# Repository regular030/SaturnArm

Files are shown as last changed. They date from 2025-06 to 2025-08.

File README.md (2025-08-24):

<p align="center">
  
  # SaturnArm - A Simple Robotic Arm
</p>

<p align="center">
  
  
  
  
  
  
  [Youtube Video](https://youtu.be/AQZ1tVmb0GA)
  
  <ul>
<p align="center">
  <br>
  BOM: https://docs.google.com/spreadsheets/d/1lf9XG99qlgez3aRTxvFln9WQ-VlTF8MQk1fM6mLnBtQ/edit?usp=sharing
    
  
</p>
    
<h2> Why did I Build This?</h2>
<p>
  While watching a NASA Mars rover in action on YouTube, I noticed how every function, including the robotic arm, was controlled through a computer interface. It made me wonder, why not use virtual reality instead, to make the experience more immersive and intuitive?
</p>

# Files 
- Chassis
  - SaturnArm.gcode.3mf
      - G-code to print out the entire arm for the Bambu Lab A1m
  - arm_pcb.step
    - The PCB's 3D model file
  - Full-Arm.f3z
    - Full Fusion/Fusion 360 file for the arm
  - bot
    - All 3D files for the bottom part of the arm    
  - middle
    - All 3D files for the middle part of the arm    
  - top
    - All 3D files for the top part of the arm
- Kicad
  - All PCB files for KiCad 8.0.5
- Firmware
  - All the Firmware files for the Pi Zero 2 W
- Unity
  -  All the Files for the VR to Arm stuff in Unity 2022.3.38f1
  -  DEPRECATED
      
<ul> </ul>
 
#  Instructions

## Building the Firmware on Raspberry Pi Zero 2 W

**1. Install Required Packages**

Open a terminal on your Pi Zero 2 W and run:
```sh
sudo apt update
sudo apt install -y git cmake g++ libopencv-dev libboost-system-dev pigpio
```

**2. Clone the Repository**
```sh
git clone https://github.com/regular030/SaturnArm
cd SaturnArm/Firmware/Arm
```

**3. Enable pigpio Daemon**
```sh
sudo systemctl enable pigpiod
sudo systemctl start pigpiod
```

**4. Build the Firmware**
```sh
mkdir build
cd build
cmake ..
make -j1
```
The executable `SaturnArm` will be created in the `build` directory.

---

## Calibration

Before using the arm, you must calibrate it:

1. **Remove the Motors:**  
   Remove the motors from the arm.

2. **Run the Firmware:**  
   Start the firmware executable under the build directory:
   ```sh
   sudo ./SaturnArm
   ```

3. **Wait for Program to Run:**  
   Wait for the Program to run, after that wait for the motors to move to 0deg. Once the motors are done moving, make sure the arms are in an upright position before attaching the motors.

---

## Main Functions

- **move_to(x, z):**  
  Move the arm to a specific (x, z) coordinate using inverse kinematics.
     ```sh
   move:(x),(y)
   ```

- **set_servo_angle(servo_number, angle):**  
  Set a specific servo (shoulder, elbow, or claw) to a given angle.
     ```sh
   servo(number):(deg)
   ```

- **emergency_stop():**  
  Immediately stop all motion and disable servos.
  ```sh
   stop
   ```
---

For more details, see the source code in `Firmware/Arm/`.

<ul> </ul>

#  TODO

- Finalize VR Support - Delayed Indefinitely

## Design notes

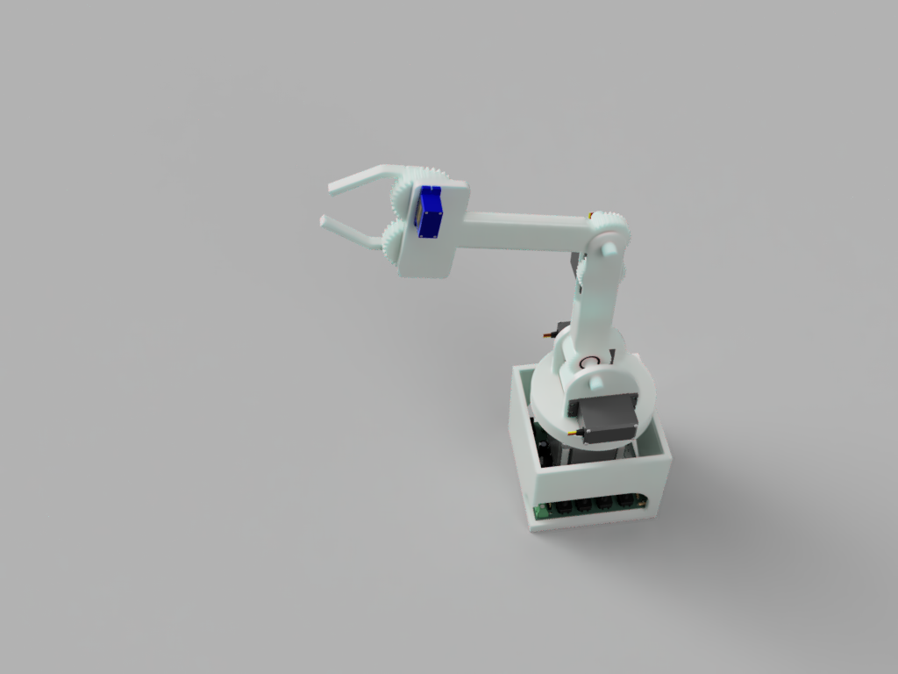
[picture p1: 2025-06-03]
Chassis/arm_2025-Jun-03_09-30-14PM-000_CustomizedView1273378670.png

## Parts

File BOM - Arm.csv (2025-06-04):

Part Name | QTY | Price Per | Link | Notes
Raspberry Pi Zero 2 W(U2) | 1 | US $24.04 | here
LM2596 (U1) | 1 | US $1.54 | here
THT 3 Pin connectors 5 pack | 1 | US $1.84 | here
THT 4 Pin connectors 5 pack | 1 | US $2.11 | here
Mg996r | 3 | US $15.49 | here | servo
Nema23 23HS5628 | 1 | US $25.05 | here
Sg90 | 1 | US $3.29 | here | mini servo
AC 110V - 220V DC 24V 8A | 1 | US $20.07 | here | psu
Rotary Encoder | 5 | US $2.72 | here
Bearing - 6800-2RS 10X19X5 | 4 | US $4.10 | here
75mm M5 screw 10 pack | 1 | US $0.99 | here
M3 M4 M5 screw and nuts pack | 1 | US $16.32 | here
1 kg of PLA white matte | 1 | US $21.87 | here
resistors Pack | 1 | US $3.20 | here | 10k + 1k
2.1mm Jack THT | 1 | US $1.35 | here
DC 24V to DC 6V | 1 | US $7.67 | here
Wire Multiple colours | 1 | US $10.98 | here | 20awg
TMC2208 | 1 | US $4.31 | here | stepper driver
Micro SD card | 1 | US $4.67 | here
Micro USB Male To USB 2.0 Female | 1 | US $2.13 | here
JLCPCB | 5 | US $2.00
Raspberry Pi Model B+ Camera Module | 1 | US $4.51 | here
Tota (Taxes + shipping): | US $151.25 (AliExpress) + USD 31.30$ Bambulab + USD $3.50 (JLC) = $186.05 USD =~ $200 USD

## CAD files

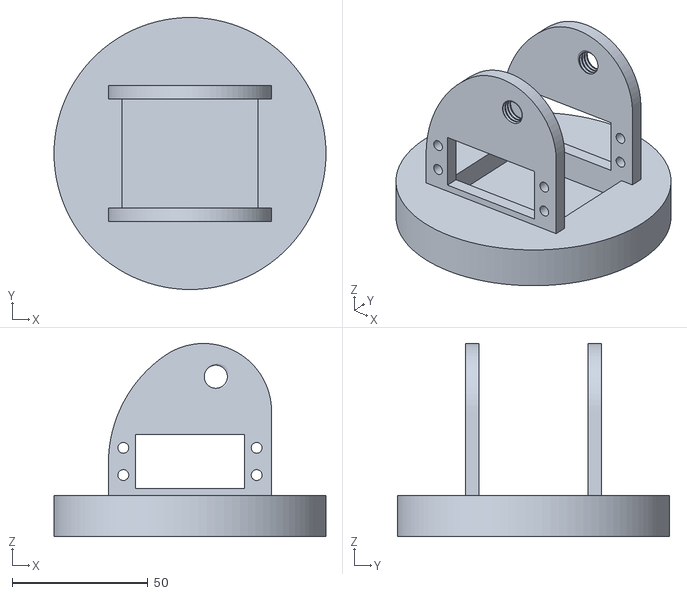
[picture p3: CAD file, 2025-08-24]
Chassis/bot/Arm_Base.stl
100.0 x 100.0 x 71.0

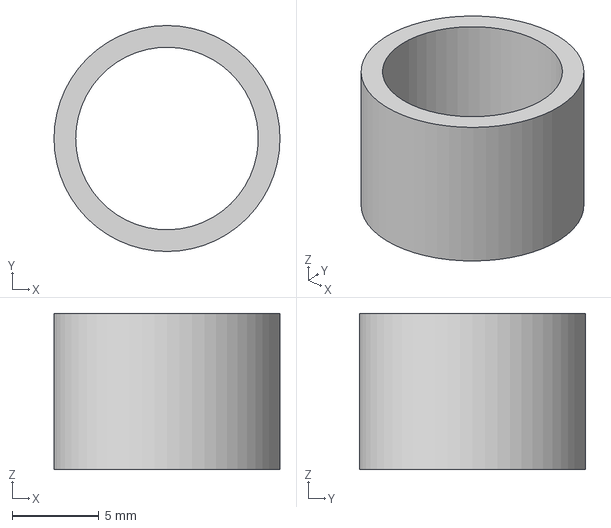
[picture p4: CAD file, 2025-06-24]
Chassis/middle/BearingHolderLow-Spacer.step
13.0 x 13.0 x 9.00 mm

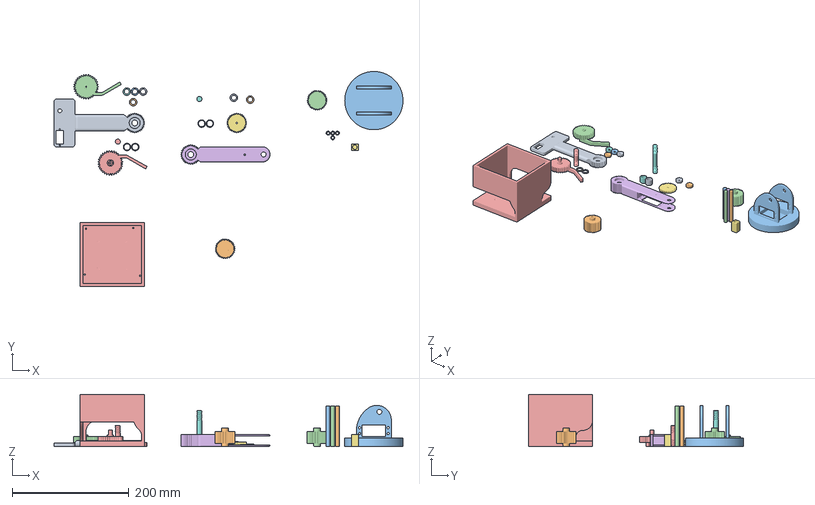
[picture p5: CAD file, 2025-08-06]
Chassis/SaturnArm.gcode.3mf
599.1 x 369.2 x 90.0 mm
arm2.stl
Nut-10mm.step x 6
TopClawL.stl
TopClawR.stl
Arm1.stl
arm-thinGear-Real v9
bearingHolder-Low v13
Arm_Base.stl
PCB_Chassis.stl
Standoff-Bot.stl x 4
Stepper-Insert v7
bearingHolder-middle.step
BearingHolderMiddle-Spacer.step x 2
BearingHolderLow-Spacer.step x 2

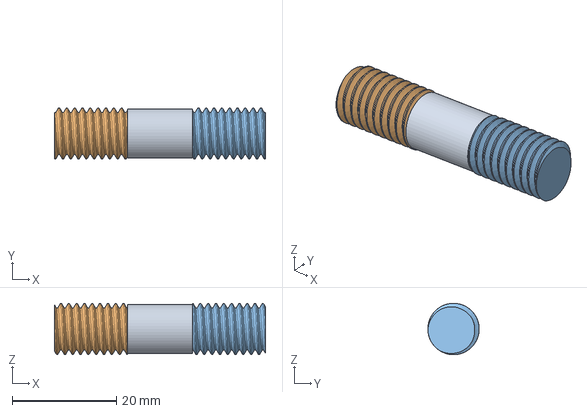
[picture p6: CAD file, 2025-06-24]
Chassis/top/bearingHolder-middle.step
40.5 x 9.86 x 9.86 mm

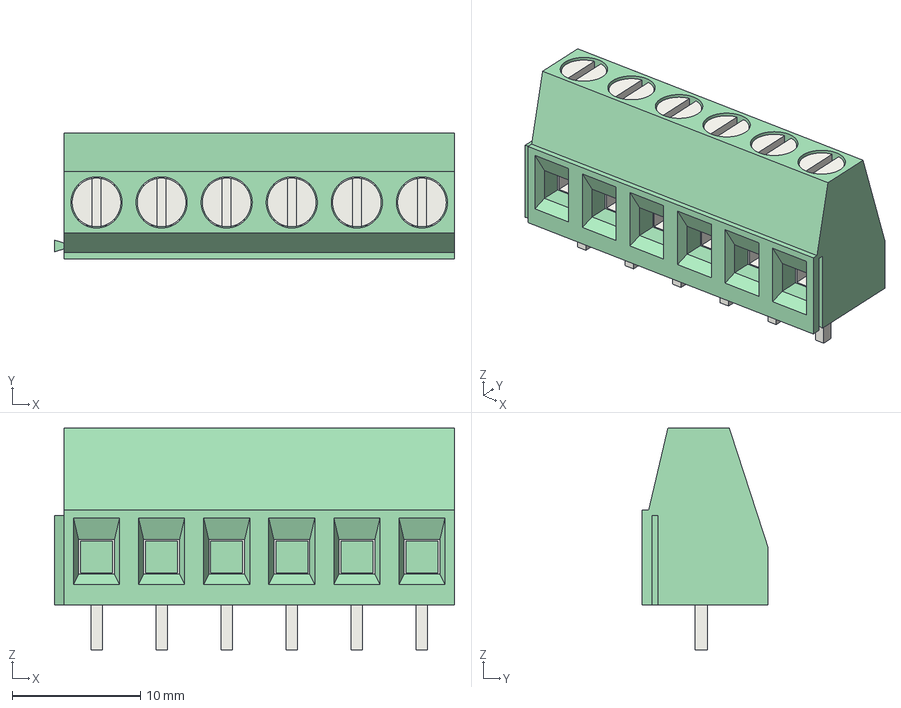
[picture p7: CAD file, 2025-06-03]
Kicad/Files Needed/3dmodels/TerminalBlock_Phoenix_MKDS-1,5-6-5.08_1x06_P5.08mm_Horizontal.step
31.2 x 9.80 x 17.3 mm

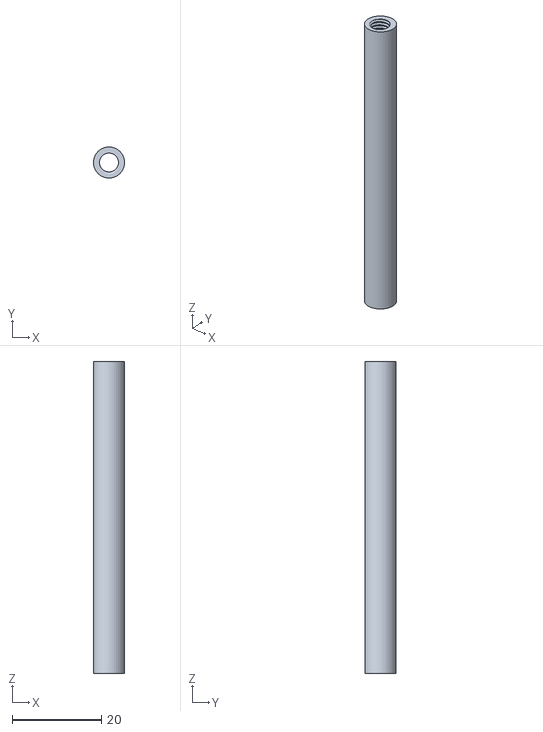
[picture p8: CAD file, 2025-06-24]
Chassis/bot/Standoff-Bot.stl
7.00 x 7.00 x 70.0

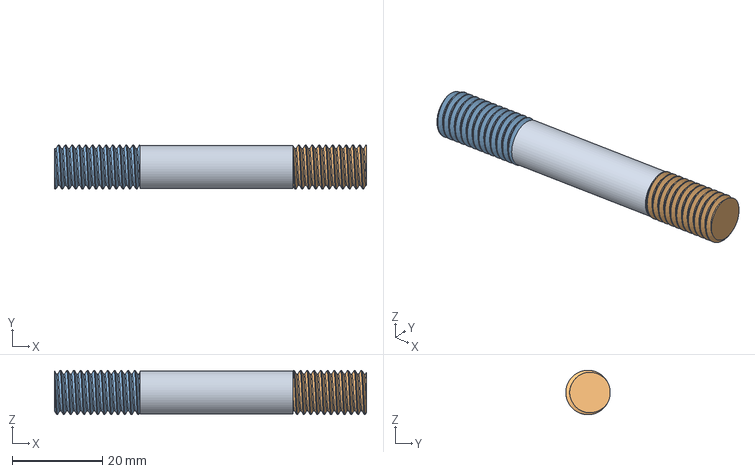
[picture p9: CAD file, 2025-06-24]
Chassis/middle/bearingHolder-Low.step
69.2 x 9.86 x 9.86 mm

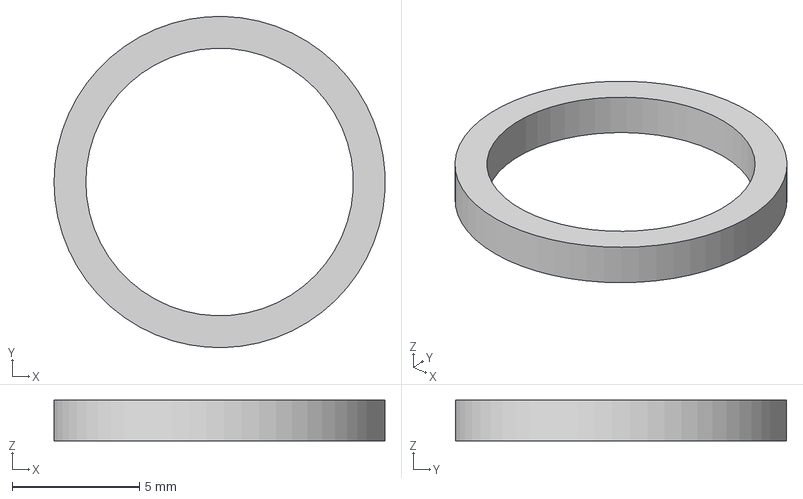
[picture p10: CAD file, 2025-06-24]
Chassis/top/BearingHolderMiddle-Spacer.step
13.0 x 13.0 x 1.60 mm

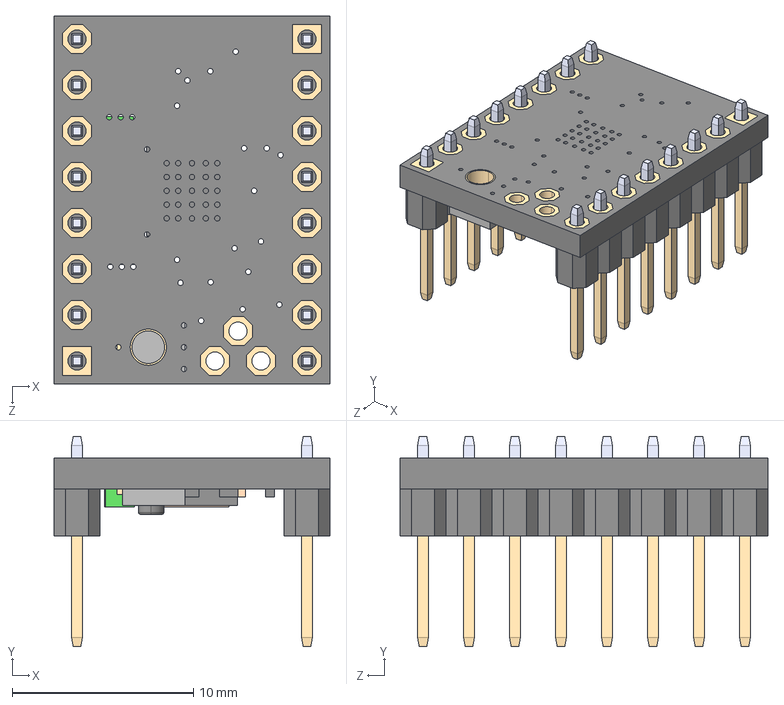
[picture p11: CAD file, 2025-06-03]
Kicad/Files Needed/3dmodels/TMC2208 SILENTSTEPSTICK--3DModel-STEP-1.STEP
15.2 x 11.6 x 20.3 mm

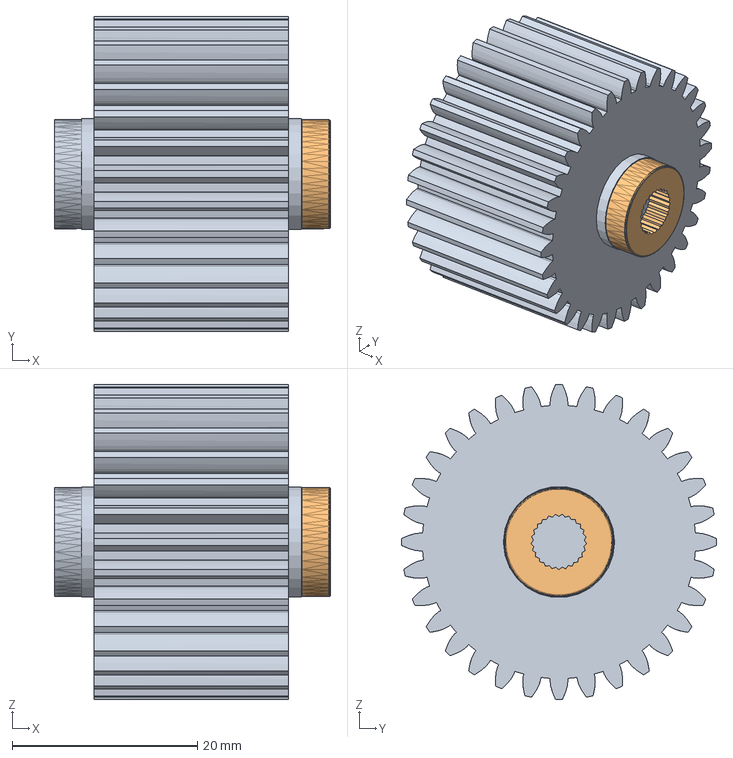
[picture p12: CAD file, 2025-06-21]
Chassis/bot/insert-motor-bot.step
29.8 x 34.0 x 34.0 mm

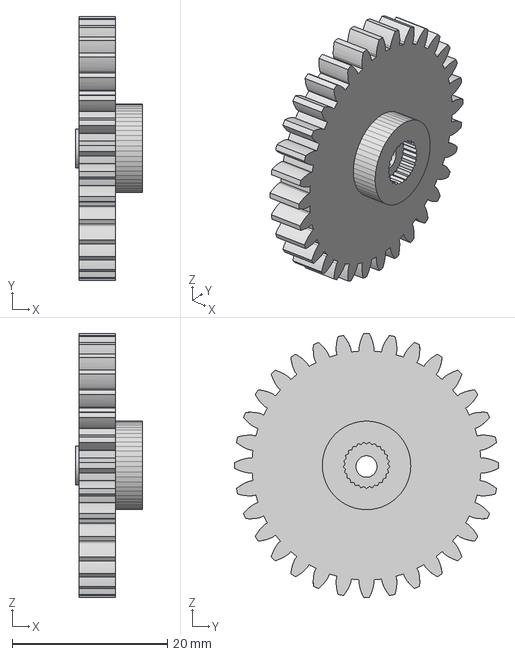
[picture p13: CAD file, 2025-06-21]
Chassis/middle/arm1-thinGear.step
8.67 x 34.0 x 34.0 mm

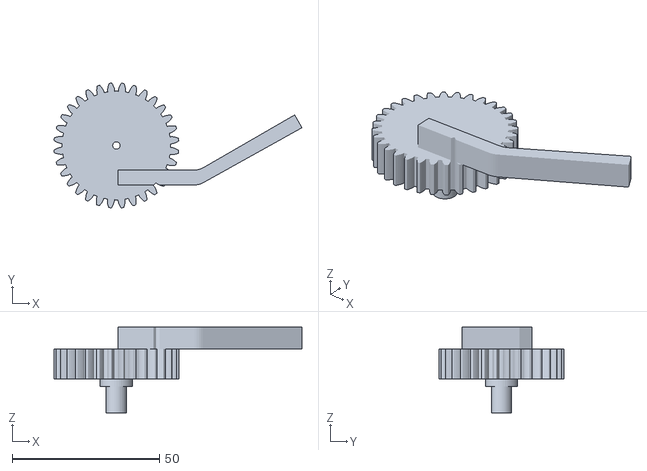
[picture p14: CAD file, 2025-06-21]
Chassis/top/TopClawR.stl
84.2 x 42.4 x 29.1

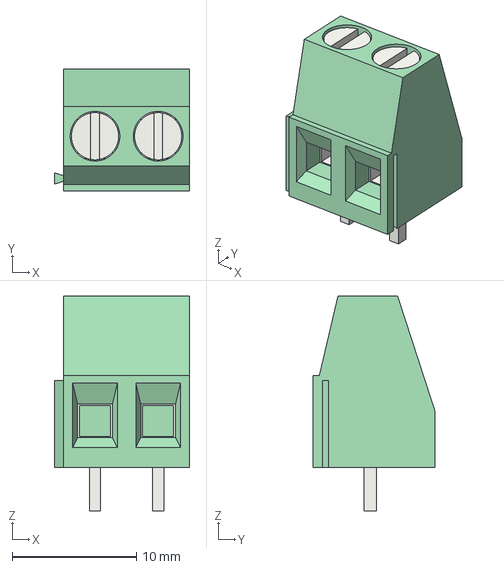
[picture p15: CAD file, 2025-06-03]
Kicad/Files Needed/3dmodels/TerminalBlock_Phoenix_MKDS-1,5-2-5.08_1x02_P5.08mm_Horizontal.step
10.9 x 9.80 x 17.3 mm

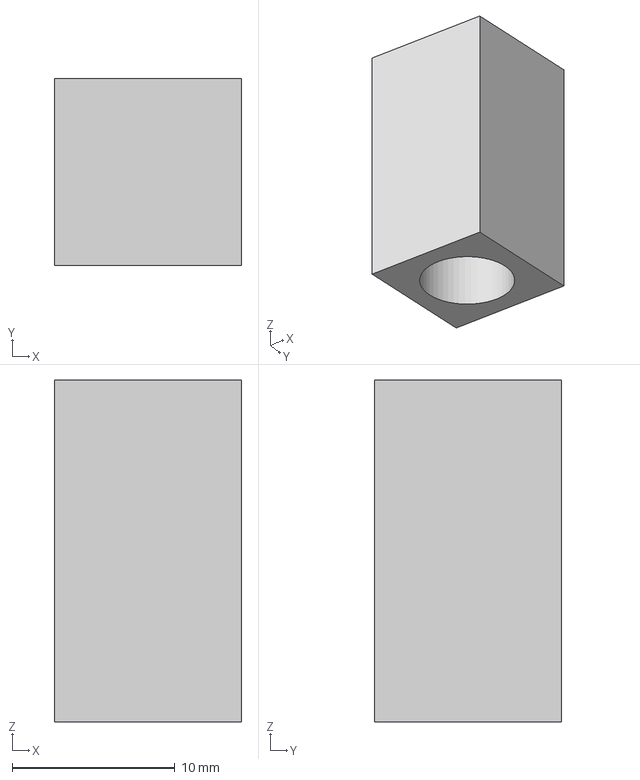
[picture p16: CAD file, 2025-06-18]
Chassis/bot/Stepper-Insert.step
11.5 x 11.5 x 21.0 mm

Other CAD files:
Chassis/top/TopClawL.stl
Kicad/Files Needed/3dmodels/TerminalBlock_Phoenix_MKDS-1,5-3-5.08_1x03_P5.08mm_Horizontal.step
Chassis/bot/PCB_Chassis.stl
Chassis/middle/Arm1.stl
Chassis/middle/Nut-10mm.step
Chassis/top/Nut-10mm.step
Chassis/top/arm2.stl
Kicad/Files Needed/3dmodels/Bourns_-_PEC11R-4220F-S0024.step
Kicad/Files Needed/3dmodels/SN74HC165N.step
Kicad/Files Needed/3dmodels/TerminalBlock_Phoenix_MKDS-1,5-4-5.08_1x04_P5.08mm_Horizontal.step
Kicad/Files Needed/3dmodels/esp32_devkit_v1_doit.step

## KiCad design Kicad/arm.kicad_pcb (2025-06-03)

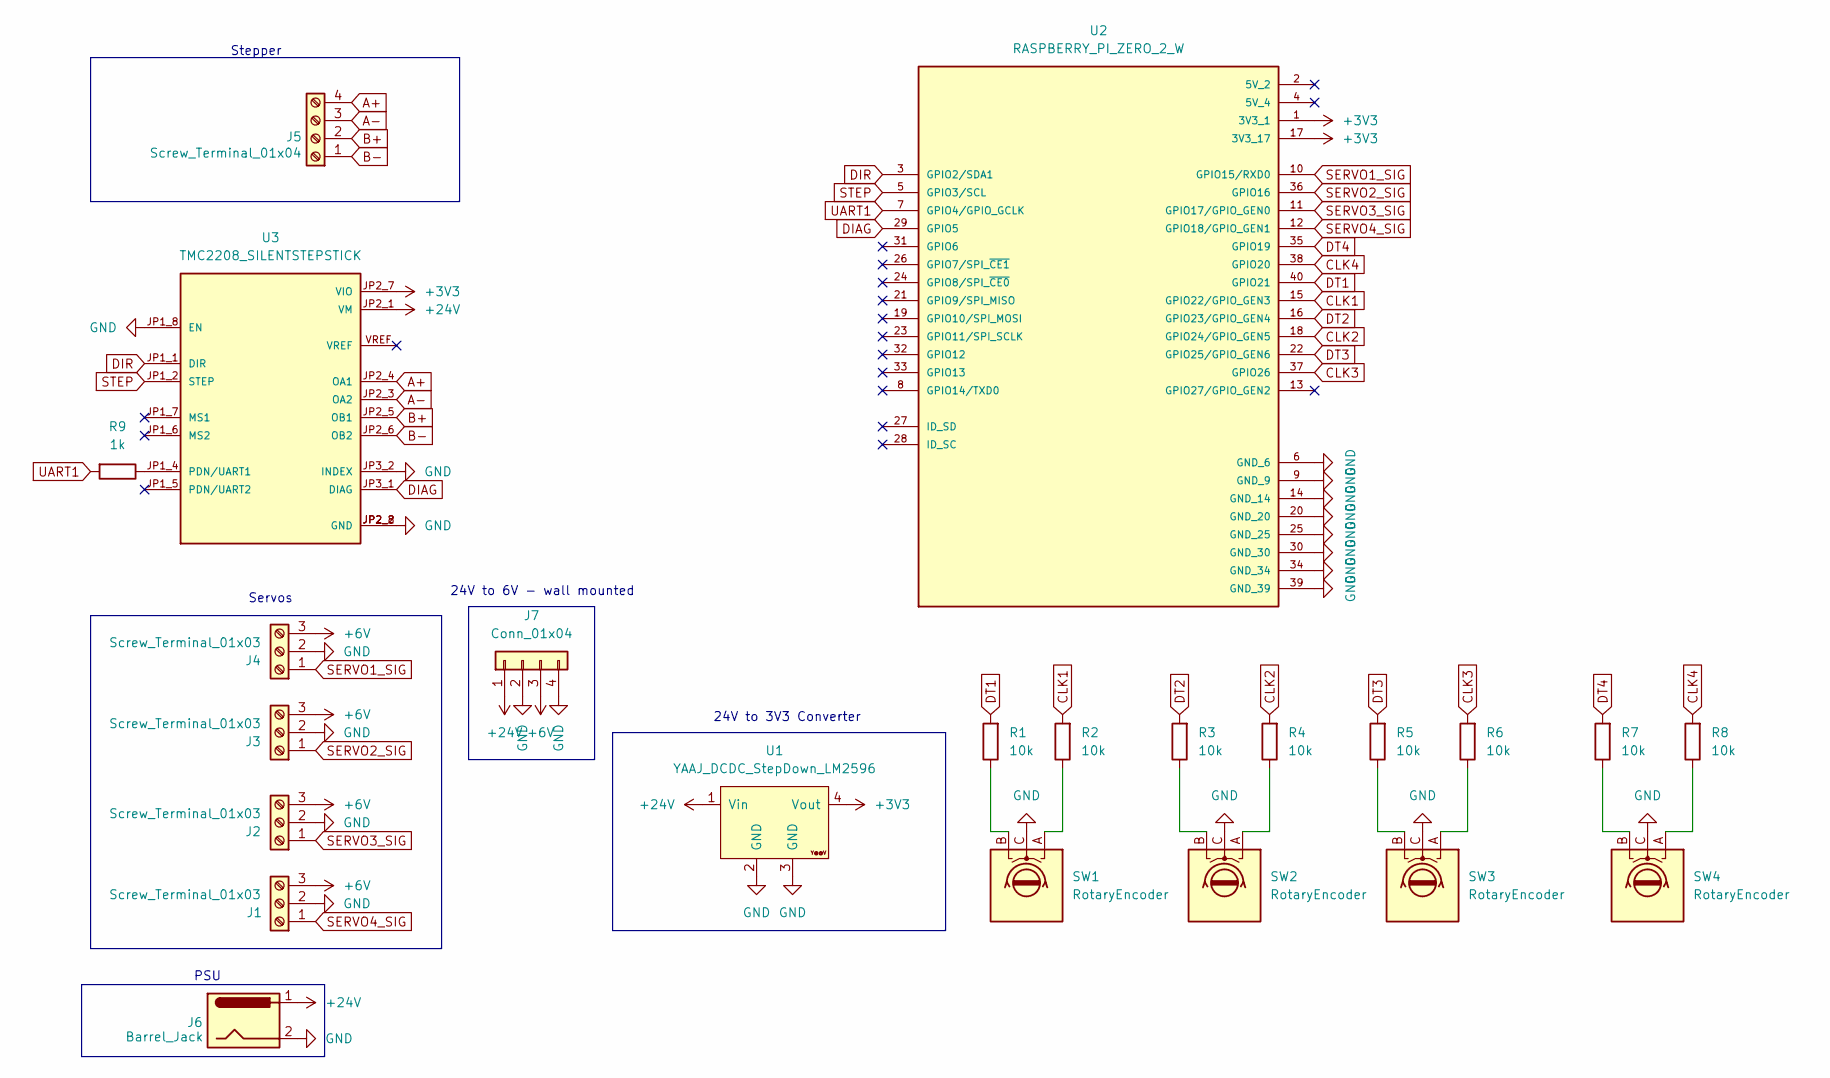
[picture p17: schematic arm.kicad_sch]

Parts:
J1, J2, J3, J4: Screw_Terminal_01x03; TerminalBlock_bornier-3_P5.08mm
J5: Screw_Terminal_01x04; TerminalBlock_bornier-4_P5.08mm
J6: Barrel_Jack; BarrelJack_Horizontal
J7: Conn_01x04; PinHeader_1x04_P2.54mm_Vertical
R1, R2, R3, R4, R5, R6, R7, R8: 10k; R_Axial_DIN0207_L6.3mm_D2.5mm_P7.62mm_Horizontal
R9: 1k; R_Axial_DIN0207_L6.3mm_D2.5mm_P7.62mm_Horizontal
SW1, SW2, SW3, SW4: RotaryEncoder; RotaryEncoder_Alps_EC11E-Switch_Vertical_H20mm
U1: YAAJ_DCDC_StepDown_LM2596
U2: RASPBERRY_PI_ZERO_2_W; MODULE_RASPBERRY_PI_ZERO_2_W; PARTREV April 2024
U3: TMC2208_SILENTSTEPSTICK; MODULE_TMC2208_SILENTSTEPSTICK

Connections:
+3V3: U1.4 (Vout), U2.1 (3V3_1), U2.17 (3V3_17), U3.JP2_7 (VIO)
+6V: J1.3, J2.3, J3.3, J4.3, J7.3
+24V: J6.1, J7.1, U1.1 (Vin), U3.JP2_1 (VM)
A+: J5.4, U3.JP2_4 (OA1)
A-: J5.3, U3.JP2_3 (OA2)
B+: J5.2, U3.JP2_5 (OB1)
B-: J5.1, U3.JP2_6 (OB2)
CLK1: R2.2, U2.15 (GPIO22/GPIO_GEN3)
CLK2: R4.2, U2.18 (GPIO24/GPIO_GEN5)
CLK3: R6.2, U2.37 (GPIO26)
CLK4: R8.2, U2.38 (GPIO20)
DIAG: U2.29 (GPIO5), U3.JP3_1 (DIAG)
DIR: U2.3 (GPIO2/SDA1), U3.JP1_1 (DIR)
DT1: R1.2, U2.40 (GPIO21)
DT2: R3.2, U2.16 (GPIO23/GPIO_GEN4)
DT3: R5.2, U2.22 (GPIO25/GPIO_GEN6)
DT4: R7.2, U2.35 (GPIO19)
GND: J1.2, J2.2, J3.2, J4.2, J6.2, J7.2, J7.4, SW1.C, SW2.C, SW3.C, SW4.C, U1.2 (GND), U1.3 (GND), U2.6 (GND_6), U2.9 (GND_9), U2.14 (GND_14), U2.20 (GND_20), U2.25 (GND_25), U2.30 (GND_30), U2.34 (GND_34), U2.39 (GND_39), U3.JP1_8 (EN), U3.JP2_2 (GND), U3.JP2_8 (GND), U3.JP3_2 (INDEX)
unnamed: R1.1, SW1.B
unnamed: R2.1, SW1.A
unnamed: R3.1, SW2.B
unnamed: R4.1, SW2.A
unnamed: R5.1, SW3.B
unnamed: R6.1, SW3.A
unnamed: R7.1, SW4.B
unnamed: R8.1, SW4.A
unnamed: R9.1, U3.JP1_4 (PDN/UART1)
SERVO1_SIG: J4.1, U2.10 (GPIO15/RXD0)
SERVO2_SIG: J3.1, U2.36 (GPIO16)
SERVO3_SIG: J2.1, U2.11 (GPIO17/GPIO_GEN0)
SERVO4_SIG: J1.1, U2.12 (GPIO18/GPIO_GEN1)
STEP: U2.5 (GPIO3/SCL), U3.JP1_2 (STEP)
UART1: R9.2, U2.7 (GPIO4/GPIO_GCLK)

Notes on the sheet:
Servos
Stepper
24V to 6V - wall mounted
24V to 3V3 Converter
PSU

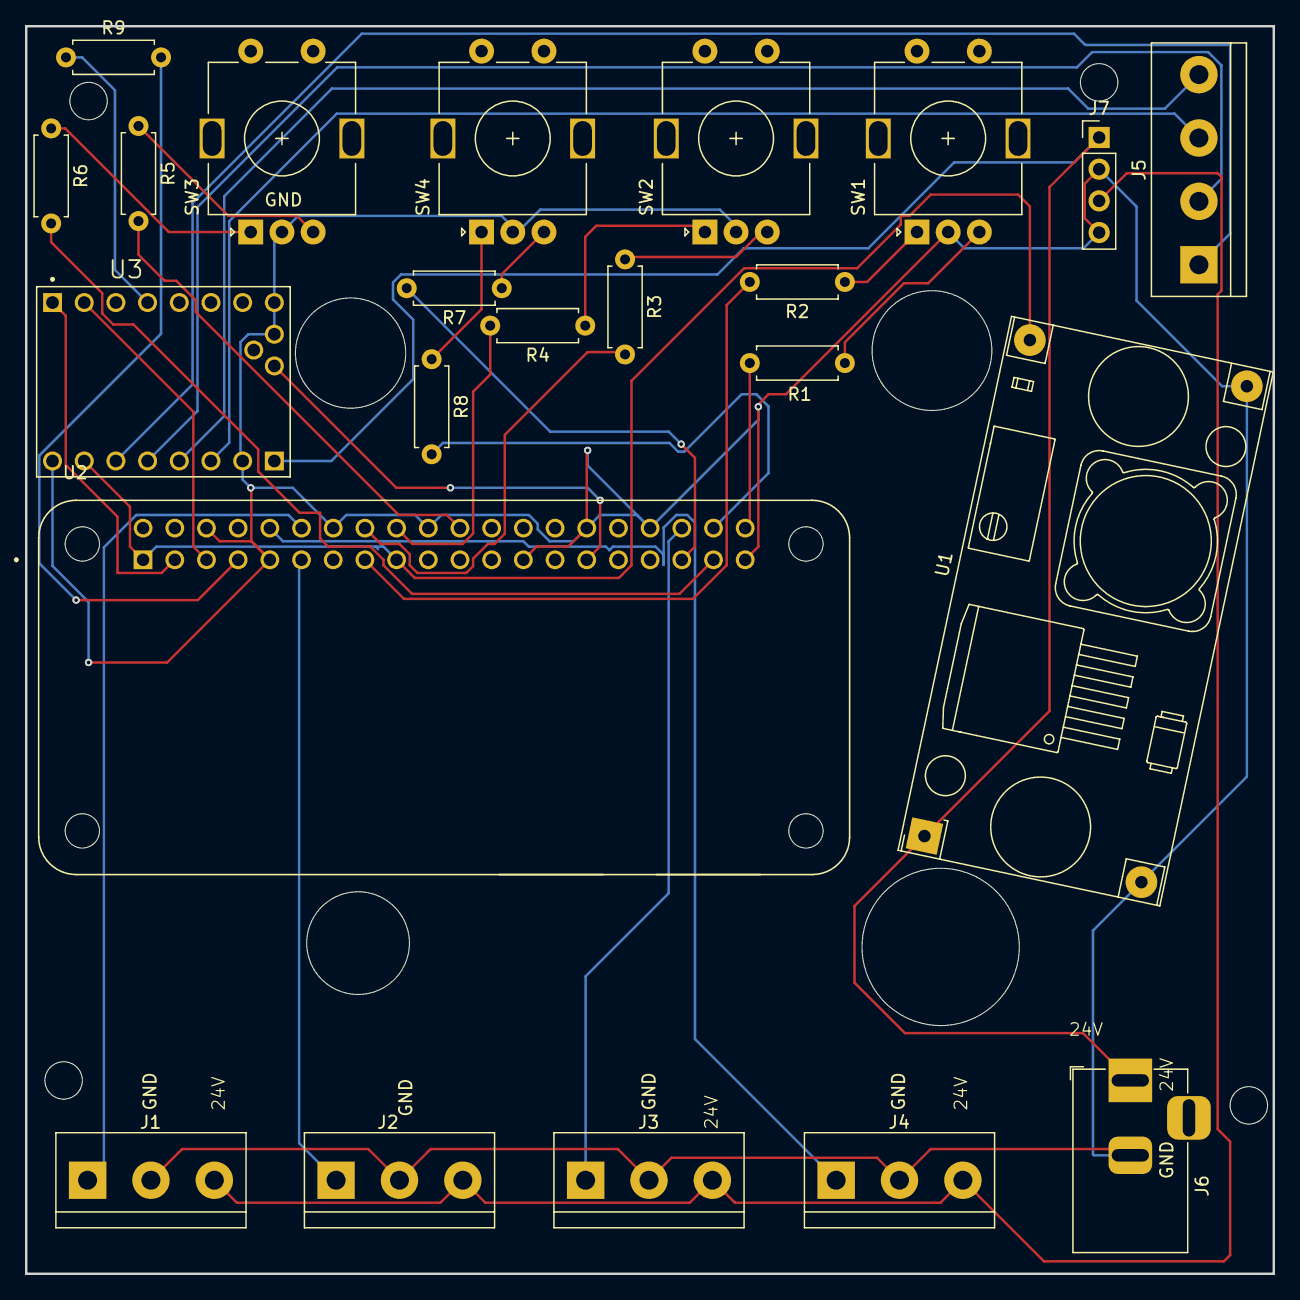
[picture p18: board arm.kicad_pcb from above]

Board: 2 copper layers, 100.0 x 100.0 mm, 23 parts (0 on the bottom side), 33 nets.

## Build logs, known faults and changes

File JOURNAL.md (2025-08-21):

---
title: "Saturn Arm"
author: "Kunshpreet"
description: "Development log for a VR-controlled robotic arm project"
---

**Total time spent thus far: 103h**

# May 25-26: Initial Concept and Design
- Created idea
- Pitched concept
- Developed rough Bill of Materials (BOM)
- **Total time spent: 4h**

# May 26-28: Arm Assembly and Design Refinements
- Finished first part of the arm
- Nearly completed second part
- Redesigned bearing holders (original design required impractical assembly)
- Identified needed PCB components:
  - 4 × 3-pin connectors for Servos
  - 1 × 4-pin connector for stepper
  - 1 × 2-pin connector for PSU
  - 3 × MG996R servos
  - M3.5 screws
  - Nema23 23HS5628 stepper + TB6600 Controller
  - SG90 servo
  - LM2596 voltage regulator (for ESP32 compatibility)
  - PSU: [AliExpress link](https://www.aliexpress.com/item/1005005763465796.html)
  - Rotary encoder
- TODO:
  - Finish second arm
  - Complete claw mechanism
  - Finalize bottom part
  - Design camera mount
  
  <br>
  
  

  </br>
  
**Total time spent: 16h**

# May 29: Structural Completion and PCB Design
- Finished all arms + claw assembly
- Improved aesthetic design
- Designed PCB (significant time spent on hole placement)
- Created stepper motor base connection with tight-tolerance square insert
- Current progress: ~60%
- TODO:
  - Complete base assembly
  - Fix 3D printed inserts
  - Finalize BOM
  - Begin coding
    <br>

 
- **Total time spent: 6h**

# May 30 - June 1: Component Updates and PCB Revision
- Arm improvements:
  - Added screw mounts to arm holders
  - Designed printable nuts for assembly
  - Created side components
- Major PCB changes:
  - Switched ESP32 → Raspberry Pi Zero W (better camera streaming)
  - Significant time spent updating PCB layout/screw holes
- TODO:
  - Design camera mount
  - Convert to wall-plug PSU
  - Add/remove rotary encoder based on space
  - Update connectors: 2-pin → PSU pins, 4-pin → 6-pin
  - Find placement for TB6600 Controller
    <br>



- **Total time spent: 10h**

# June 2: Power System and Controller Updates
- Implemented changes:
  - Converted to wall-plug PSU
  - Added second rotary encoder
  - Updated connectors: 2-pin → PSU, 4-pin → 6-pin
  - Replaced TB6600 with space-saving TMC2208 controller
- TODO:
  - Finalize camera mounting solution
  - Complete official BOM
  - Start coding base functionality
      <br>



- **Total time spent: 4h**

# June 2: Github Stuff
- Created Journal.md
- Finished BOM
- TODO:
  - Add Camera to BOM
  - Finalize camera mounting solution
  - Start coding base functionality
  - Start coding VR → Arm Pose in Unity
- **Total time spent: 3h**

# June 2-4: Coding
- Added rotary encoder support
  - Encoder 1 → controls Joint 1
  - Encoder 2 → controls Joint 2
  - Encoder 3 → controls the claw
  - Encoder 4 → controls base (stepper/rotation)
- Implemented inverse kinematics with safety checks
  - Enforces ±90° range from vertical (coded as 90°)
  - Restricts x ∈ [-5.5, 5.5] if y ≥ -2 cm
- Added movement validation system
  - Only moves to reachable coordinates within the arm’s physical limits
  - Displays an error if the point is unreachable
- New command features
  - Supports input like x:5,y:8,z:-2
  - stop command halts all motors immediately
- Maintains stable claw orientation (always facing downward)
- TODO:
  - Finalize camera mounting solution
  - Start coding VR → Arm Pose in Unity
**Total time spent: 10h**

# June 4-10: Coding for Pi Zero 2 W to Unity VR
- Ported legacy code to Pico SDK environment  
- Implemented hardware abstraction layer for:  
  - Servo/stepper motor control  
  - Rotary encoder feedback  
- Verified all hardware functionality
- Built a lightweight TCP server using lwIP 
- Added WebSocket support for real-time control  
- Key endpoints:  
  | Endpoint | Function |  
  |----------|----------|  
  | `/move`  | Coordinate-based arm movement |  
  | `/direct`| Raw servo control |  
  | `/encoders` | Live position feedback |  
  | `/camera` | MJPEG video stream (10 FPS) |
- Unity Features:  
  - Controller-triggered calibration  
  - 1:1 movement mapping (VR → Physical Arm)  
  - Real-time camera display  
  - Connection status UI
 - TODO:
   - Find out where to put the camera :sob:
<br>

**Total time spent: 20h**

# Aug 1-20: Hardware Building, Testing and Debugging

- **Failures & Issues**
  - Burned 1 × Raspberry Pi Zero 2 W (likely due to incorrect LM2596 calibration)  
  - 1 PCB failed due to soldering issues (not design-related)  
  - Accidentally ordered 360° continuous rotation servos instead of 180° positional ones  
  - Stripped the internal gear of TWO 180 ° servo during torque testing  
  - Original 3D-printed gears failed under load, requiring redesign  

- **Fixes & Improvements**
  - Learned an important tip: always calibrate the LM2596 before powering sensitive boards  
  - Fully soldered all working boards and connectors  
  - Updated firmware with expanded debugging tools (serial logs, error states, power monitoring)  
  - 3D printed replacement parts to strengthen gear assemblies  

- **Integration & Results**
  - Ran the PCB successfully after assembly  
  - Verified stable communication between Raspberry Pi and motor drivers  
  - Completed end-to-end integration of PCBs, motors, and encoders  
  - System reached the stage of a stable working prototype  
  - Project will be on hold until I get another 180-degree servo to implement VR support

**Total time spent: 30h**

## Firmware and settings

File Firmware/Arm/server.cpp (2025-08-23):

#include "arm_controller.h"
#include "camera.h"
#include <boost/beast.hpp>
#include <boost/beast/websocket.hpp>
#include <boost/asio.hpp>
#include <thread>
#include <atomic>
#include <iomanip>
#include <sstream>
#include <fstream>

namespace beast = boost::beast;
namespace http = beast::http;
namespace net = boost::asio;
using tcp = net::ip::tcp;

constexpr int CAM_WIDTH = 640;
constexpr int CAM_HEIGHT = 480;
constexpr int CAM_FPS = 10;

std::atomic<ArmController*> active_arm{nullptr};
std::atomic<bool> running{true};

void send_http_response(tcp::socket& socket, http::status status, 
                        const std::string& content_type, const std::string& body) {
    http::response<http::string_body> res{status, 11};
    res.set(http::field::content_type, content_type);
    res.body() = body;
    res.prepare_payload();
    http::write(socket, res);
}

void send_websocket_message(beast::websocket::stream<tcp::socket>& ws, 
                            const std::string& message) {
    ws.write(net::buffer(message));
}

void handle_websocket(tcp::socket socket, ArmController& arm, Camera& camera) {
    try {
        beast::websocket::stream<tcp::socket> ws{std::move(socket)};
        ws.accept();
        
        active_arm = &arm;
        std::cout << "WebSocket connection established" << std::endl;
        
        beast::flat_buffer buffer;
        
        while (running) {
            // Read message
            buffer.clear();
            ws.read(buffer);
            std::string cmd = beast::buffers_to_string(buffer.data());
            
            // Process command
            if (cmd.find("move:") == 0) {
                float x, z;
                if (sscanf(cmd.c_str(), "move:%f,%f", &x, &z) == 2) {
                    arm.move_to(x, z);
                }
            }
            else if (cmd == "calibrate") {
                arm.calibrate();
            }
            else if (cmd == "stop") {
                arm.emergency_stop();
            }
            
            // Send encoder positions
            std::ostringstream oss;
            oss << "encoders:"
                << arm.get_stepper_position() << ","
                << arm.get_base_position() << ","
                << arm.get_joint2_position() << ","
                << arm.get_claw_position();
            send_websocket_message(ws, oss.str());
            
            std::this_thread::sleep_for(std::chrono::milliseconds(50));
        }
    } 
    catch (...) {
        std::cerr << "WebSocket connection closed" << std::endl;
        active_arm = nullptr;
    }
}

void handle_camera_stream(tcp::socket socket, Camera& camera) {
    if (!camera.is_initialized() && !camera.init()) {
        send_http_response(socket, http::status::internal_server_error, 
                           "text/plain", "Camera initialization failed");
        return;
    }
    
    try {
        beast::flat_buffer buffer;
        http::request<http::string_body> req;
        http::read(socket, buffer, req);
        
        http::response<http::string_body> res{
            http::status::ok,
            req.version(),
            "Streaming started"
        };
        res.set(http::field::content_type, "multipart/x-mixed-replace; boundary=frame");
        http::write(socket, res);
        
        std::cout << "Starting camera stream" << std::endl;
        
        while (running) {
            std::vector<uchar> jpeg_buffer;
            if (!camera.capture_frame(jpeg_buffer)) {
                std::this_thread::sleep_for(std::chrono::milliseconds(100));
                continue;
            }
            
            std::ostringstream header;
            header << "--frame\r\n"
                   << "Content-Type: image/jpeg\r\n"
                   << "Content-Length: " << jpeg_buffer.size() << "\r\n\r\n";
            
            net::write(socket, net::buffer(header.str()));
            net::write(socket, net::buffer(jpeg_buffer));
            
            std::this_thread::sleep_for(std::chrono::milliseconds(1000/CAM_FPS));
        }
    }
    catch (...) {
        std::cerr << "Camera stream terminated" << std::endl;
    }
}

void handle_http_request(tcp::socket socket, ArmController& arm, Camera& camera) {
    try {
        beast::flat_buffer buffer;
        http::request<http::string_body> req;
        http::read(socket, buffer, req);
        
        std::string target = req.target().to_string();
        std::cout << "HTTP Request: " << target << std::endl;
        
        if (target == "/") {
            // Serve simple HTML control interface
            std::string html = R"(
            <html><body>
            <h1>SaturnArm Control</h1>
            <a href="/camera">Camera Stream</a><br>
            <a href="/calibrate">Calibrate Arm</a><br>
            <a href="/stop">Emergency Stop</a>
            </body></html>
            )";
            send_http_response(socket, http::status::ok, "text/html", html);
        }
        else if (target == "/camera") {
            handle_camera_stream(std::move(socket), camera);
        }
        else if (target == "/calibrate") {
            arm.calibrate();
            send_http_response(socket, http::status::ok, "text/plain", "Calibration complete");
        }
        else if (target == "/stop") {
            arm.emergency_stop();
            send_http_response(socket, http::status::ok, "text/plain", "Emergency stop activated");
        }
        else if (target.find("/move") == 0) {
            float x = 0, z = 0;
            size_t pos = target.find('?');
            if (pos != std::string::npos) {
                std::string params = target.substr(pos + 1);
                sscanf(params.c_str(), "x=%f&z=%f", &x, &z);
                arm.move_to(x, z);
            }
            send_http_response(socket, http::status::ok, "text/plain", "Move command received");
        }
        else {
            send_http_response(socket, http::status::not_found, "text/plain", "404 Not Found");
        }
    }
    catch (...) {
        // Ignore connection errors
    }
}

int main() {
    // class DummyCamera : public Camera {
    // public:
    //     DummyCamera() : Camera(0, 0) {}
    //     bool init() { return false; }
    //     bool capture_frame(std::vector<unsigned char>&) { return false; }
    // };

    // DummyCamera dummy_camera;

    std::cout << "Skipping WiFi credential retrieval\n";

    ArmController arm;
    if (!arm.init()) {
        std::cerr << "FATAL: Arm initialization failed\n";
        return 1;
    }

    // Camera camera(CAM_WIDTH, CAM_HEIGHT);
    // if (!camera.init()) {
    //     std::cerr << "WARNING: Camera initialization failed - streaming disabled\n";
    // }

    // Terminal command thread
    std::thread terminal_thread([&arm]() {
        std::string line;
        while (running) {
            std::cout << "> ";
            if (!std::getline(std::cin, line)) break;

            if (line == "stop") {
                arm.emergency_stop();
                std::cout << "Emergency stop activated.\n";
            } else if (line == "calibrate") {
                arm.calibrate();
                std::cout << "Calibration complete.\n";
            } else if (line.rfind("move:", 0) == 0) {
                float x, z;
                if (sscanf(line.c_str(), "move:%f,%f", &x, &z) == 2) {
                    arm.move_to(x, z);
                    std::cout << "Moving to (" << x << ", " << z << ")\n";
                } else {
                    std::cout << "Invalid move format. Use move:x,z\n";
                }
            } else if (line == "status") {
                std::cout << "Encoders → Stepper: " << arm.get_stepper_position()
                          << " | Base: " << arm.get_base_position()
                          << " | Joint2: " << arm.get_joint2_position()
                          << " | Claw: " << arm.get_claw_position() << "\n";
            } else if (line == "exit") {
                running = false;
                break;
            } else if (line == "testservos") {
                arm.test_servos();
            } else if (line.rfind("servo", 0) == 0) {
                int servo_num, angle;
                if (sscanf(line.c_str(), "servo%d:%d", &servo_num, &angle) == 2) {
                    arm.set_servo_angle(servo_num, angle);
                } else {
                    std::cout << "Invalid format. Use: servoN:angle (e.g. servo1:90)\n";
                }
            } else {
                std::cout << "Unknown command.\n";
            }
        }
    });

    // Networking server
    net::io_context ioc;
    tcp::endpoint endpoint(net::ip::tcp::v4(), 80);
    tcp::acceptor acceptor(ioc, endpoint);

    std::cout << "SaturnArm control server running on port 80\n";

    while (running) {
        tcp::socket socket(ioc);
        acceptor.accept(socket);

    //     std::thread([s = std::move(socket), &arm, &camera]() mutable {
    //         try {
    //             beast::tcp_stream stream(std::move(s));
    //             beast::flat_buffer buffer;
    //             http::request_parser<http::empty_body> parser;
    //             parser.eager(false);
    //             http::read_header(stream, buffer, parser);
    //             auto req = parser.get();

    //             std::cout << "Connection received for: " << req.target() << "\n";

    //             if (req.target() == "/camera") {
    //                 handle_camera_stream(stream.release_socket(), camera);
    //             } else if (beast::websocket::is_upgrade(req)) {
    //                 handle_websocket(stream.release_socket(), arm, camera);
    //             } else {
    //                 handle_http_request(stream.release_socket(), arm, camera);
    //             }
    //         } catch (const std::exception& e) {
    //             std::cerr << "Connection error: " << e.what() << "\n";
    //         } catch (...) {
    //             std::cerr << "Unknown connection error\n";
    //         }
    //     }).detach();
    }

    terminal_thread.join(); // wait for terminal thread before exiting
    return 0;
}

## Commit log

2025-06-03 added gerber files
    [arm-B_Cu.gbr, arm-B_Mask.gbr, arm-B_Paste.gbr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]
2025-06-04 Added Full-Arm.f3z
2025-06-04 added the basic arm control
2025-06-10 added code for arm--> unity (although very theortical it mostly works still need to test on physical)
2025-06-10 unity wants to upload these 🥀
2025-06-18 updated stepper insert
    [SaturnArm.gcode.3mf, Stepper-Insert.step]
2025-06-21 updated gears so instead of replacing the actual gear, i just mount it, updated stls/steps + 3mf file
    [SaturnArm.gcode.3mf, TopClawL.stl, TopClawR.stl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]
2025-06-24 updated 3D files + removed old code and currently migrating it from pi pico -> pi zero
    [BearingHolderLow-Spacer.step, BearingHolderMiddle-Spacer.step, SaturnArm.gcode.3mf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]
2025-08-04 added servo test
2025-08-06 added min and max def
    [SaturnArm.gcode.3mf]
2025-08-07 updated kinematics

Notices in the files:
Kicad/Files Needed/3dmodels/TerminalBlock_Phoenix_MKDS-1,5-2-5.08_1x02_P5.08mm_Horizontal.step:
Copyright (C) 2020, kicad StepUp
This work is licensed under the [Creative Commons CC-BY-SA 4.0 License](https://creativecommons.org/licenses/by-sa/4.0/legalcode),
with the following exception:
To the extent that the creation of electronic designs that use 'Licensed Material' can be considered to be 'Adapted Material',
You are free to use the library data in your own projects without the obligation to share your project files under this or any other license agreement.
